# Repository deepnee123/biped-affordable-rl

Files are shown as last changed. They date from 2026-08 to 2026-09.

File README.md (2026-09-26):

# Low-Cost Bipedal Robot via Reinforcement Learning

A personal passion project focused on achieving robust bipedal locomotion using highly accessible, 3D-printed hardware, and machine learning control.

## Overview

This project aims to bridge the **Sim-to-Real** gap for low-cost, hobby-grade bipedal robotics. While high-end humanoid robots rely on multi-thousand-dollar custom actuators, this design explores how advanced **Reinforcement Learning (RL)** policies can compensate for physical hardware limitations. Uses digitigrade locomotion(fun fact: animals like ostriches don't actually have inverted knees, it's their ankle). 

---

## Current Project Status

- [x] **CAD & Structural Design:** Initial physical architecture conceptualized and modeled. 

- [x] **Hardware Prototyping:** Fabricated and assembled a single-leg testbed to validate software integration, joint range of motion, and motor actuation. Second leg to be fabricated after I receive the funds(hopefully)
- [x] **Simulation Environment Setup:** Porting robot kinematics to **Genesis World**. Simplified model for training: 

  - ~~*In Progress:* Fixing URDF joint limits, collision meshes, and inertia tensors to eliminate mesh explosions during physics step iterations.~~
  - ~~*In Progress:* URDF was too hard to deal with so switched over to MJCF successfully, now loads in MuJoCo visualizer perfectly. adjusted all parameters for motors, friction, weight etc for accuracy~~
Screenshot from 2026-09-06 18-59-11

- [/] **RL Policy Training:** Training locomotion policies in simulation using domain randomization.
  - currently training all movesets, planning on deploying into robot after I am able to fund and finish the hardware build.
  - implementing domain randomization such as variable COM and actuator friction 
- [ ] **Sim-to-Real Deployment:** Flashing trained policy weights to hardware for real-world locomotion tests.

please check these out! 
current training progress videos here!:

[here:](https://www.youtube.com/watch?v=r23alA2GN7E)
[randomized vector commands for full moveset here](https://www.youtube.com/watch?v=8FQqMWRTSfI)

## System Architecture

Hardware schematic:


### Hardware Specifications
* **Actuators:** custom BLDC actuators utilizing a high reduction 17:1 cycloidal drive in order to gear down a cheap drone 360kv BLDC motor from Aliexpress. Each actuator uses odrive mini motor controller clones also from aliexpress. Each motor controller uses Odrive 3.6 firmware uploaded using Odrive tool. [Click here for great motor controller setup tutorial](https://github.com/justlovescience/MKS-XDRIVE-MINI), make sure to setup in accordance to the motor you are using. In the future I may consider creating custom pcb's for motor controls, hopefully decreasing cost even more, but that is a project in it of itself.
* **Microcontroller / Brain:** ESP32, depending on how software training goes I may switch to ESP 32 CAM so the robot can see. talks to motors through a CAN wire going to all motor controllers
* **Power Delivery:** 6s 2200 mAH LiPo battery
* **Sensors:** 
  * Inertial Measurement Sensor(IMU) MPU 9250
  * Built in magnetic encoders on motor controllers 

### Software & Training Stack
* **CAD Design:** [Onshape]https://cad.onshape.com/documents/8bf57c6be62972ed6d80fc07/w/9d44f84c666fceecad986cd8/e/5c78cbb988f68fd2f32a2769
* **Simulation Engine:** [Genesis World Sim](https://github.com/Genesis-Embodied-AI/genesis-world)
* **Robot Description:** ~~Custom URDF model using Onshape to URDF tool~~ changed to using MJCF file since it supports parallel linkages without hassle and is also supported by Genesis world.

## Design Constraints & Engineering Goals

* **Affordable Bill of Materials (BOM):** Target total cost **under $1,200**, utilizing readily available consumer components sourced via Amazon and AliExpress.
* **Accessiblity:** Fully 3D-printable structural components optimized for cheap materials(PC PETG blend) without requiring specialized CNC aluminum parts.
* **"Blind" Locomotion:** Rely exclusively on IMU body orientation and joint state feedback to maintain balance.
* **Dynamic Movement:** Develop policy reward functions capable of transitioning the robot through walking, running, and jumping states while preserving balance.

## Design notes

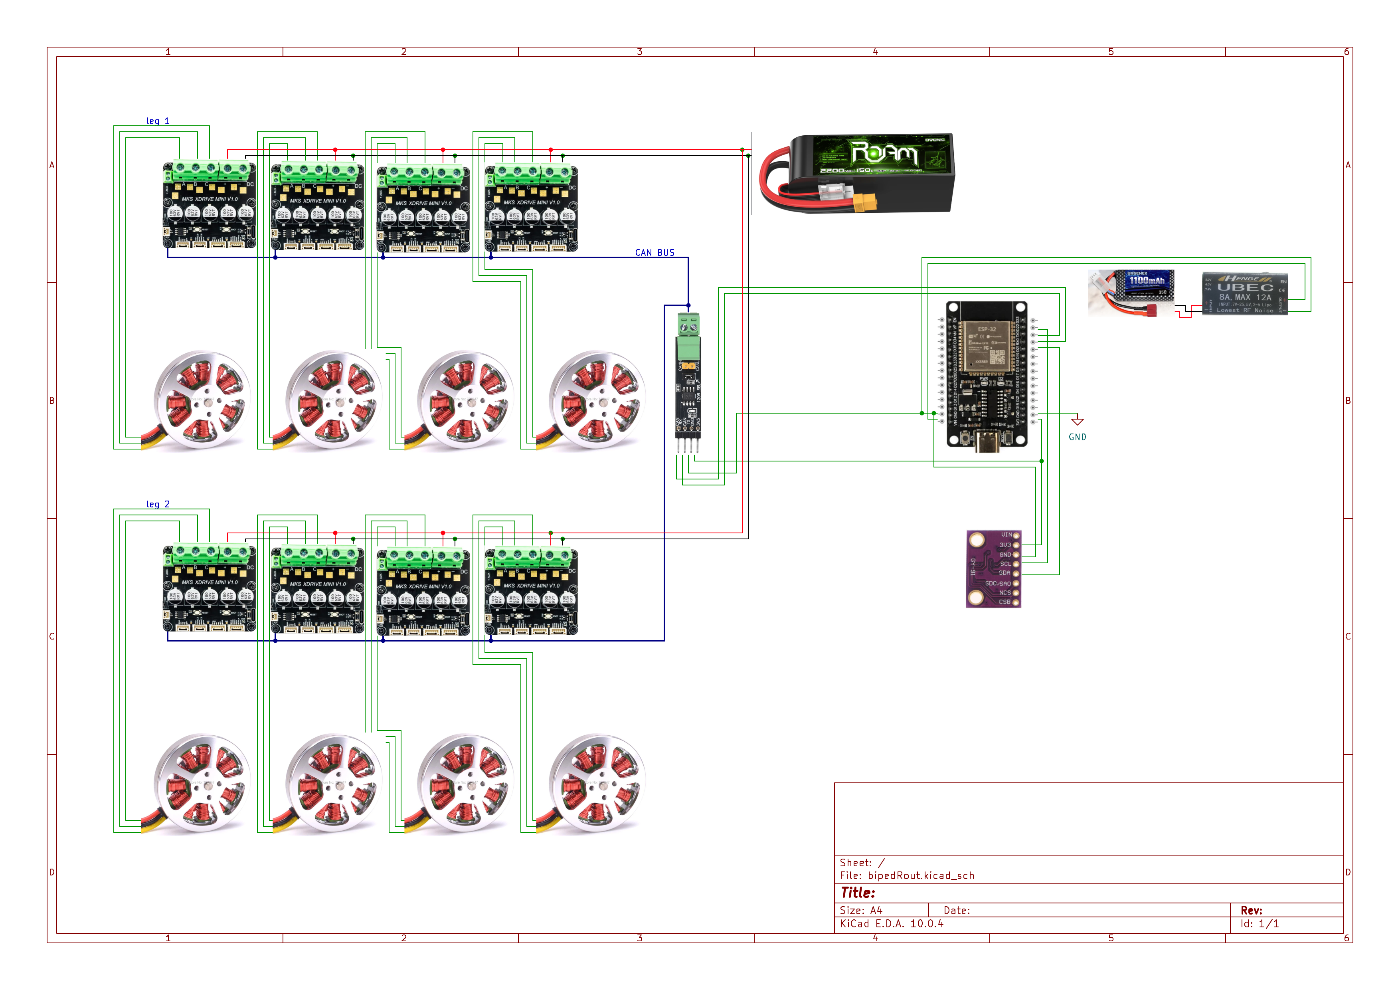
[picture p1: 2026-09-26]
image.png

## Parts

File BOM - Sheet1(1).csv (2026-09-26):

name | price(total) | quantity | brand/seller | total:
brass inserts | 13.99 | 1
2s lipo 1100 mAH | 20 | 1
3x ESP32 devkitC | 16.99 | 1
Heat shrinks | 5.99
roll of 12 awg wire | 15.99
20x 6809ZZ bearings | 47.58 | 1 | uxcell
20x Diametric magnets | 19.33 | 1 | Eliveshown
6s Lipo Charger | 29.99 | 1 | ISDT
6s Lipo 2200mAH | 34.99 | 1 | Ovonic
10x XT60 connector male + female | 9.99 | 1 | Tosiicop
2x PC filament 1kg | 47.98 | 1 | CC3D
m3 screws long | 8.99 | 1
8x 5010 360kv motor | 120 | 1
8x MKS xdrive mini | 400 | 1 | Makerbase
2x steel linkage | 15.28 | 1 | MECCANIXITY
80x MR106-RS bearings | 48.95 | 1 | Sackorange
20x 6701-2RS bearings | 19.58 | 1 | uxcell
SN65HVD230 | 7.99 | 1
misc screws/washers/nuts, soldering iron, etc | 67
 |  |  |  | 950.61

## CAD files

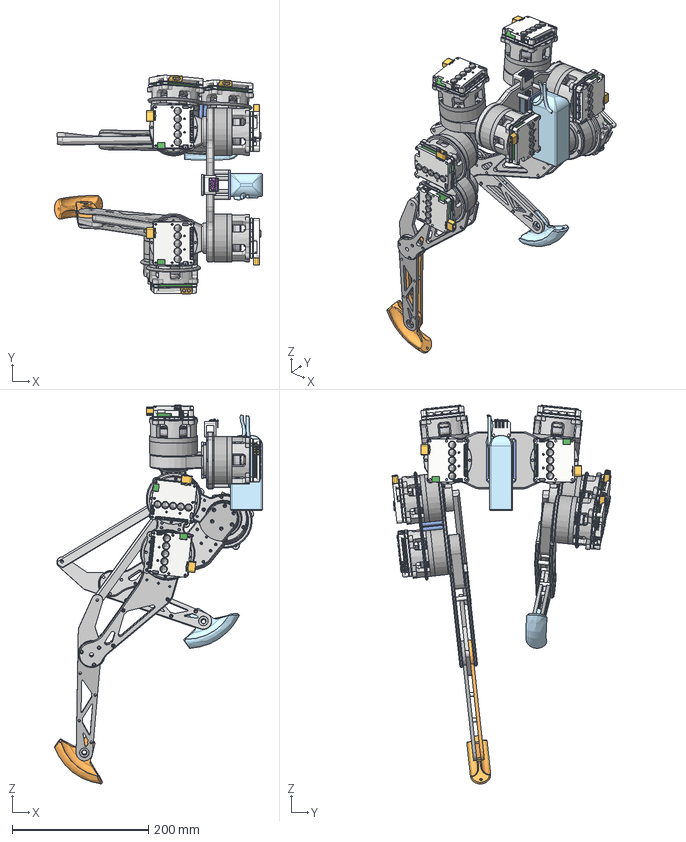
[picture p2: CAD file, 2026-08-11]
full assembly v3.step
305.0 x 320.7 x 555.5 mm
mounting
spacer x 4
cover
foot
upper leg spacer x 8
joint x 4
insert side x 2
linkage x 2
mid leg spacer x 4
screw side x 2
insert side lower leg
screwside
actuator mount x 4
lower leg spacer x 4
screw side lower leg
motor mount x 2
????? ?? ?????? 5010 x 8
?????? ?? ?????? 5010 x 8
insertside x 2
linkage attachement x 2
screw side lower leg-Mirrored
screwside-Mirrored
insert side lower leg-Mirrored
foot-Mirrored
SM02B-GHS-TB x 40
SM06B-GHS-TB x 144
SM05B-GHS-TB x 128
mks odrive mini xt60 x 64
Contact x 16
Housing x 8
1-copper x 768
Board x 56
16-copper x 96
16-soldermask x 8
1-soldermask x 8
capicitor_10x10.5x4 x 40
Base_?10Capacitor x 40
Cover x 16
Terminal x 64
Stem x 16
Frame x 16
42899.f3d x 8
632722110112_Pin_2 x 128
632722110112_Cap x 8
632722110112_Pin_1 x 32
632722110112_Pin_3 x 32
632722110112_Shielding_3 x 16
632722110112_Shielding_2 x 16
632722110112_Shielding x 8
632722110112_Housing x 8
PIN x 30
RESISTOR1_2 x 11
PCB
RESISTOR2-32_2 x 2
TRANSISTOR_3-LEG_2
RECTANGULARCHIP_2
BUTTONFLASH-13_2 x 2
BUTTONFLASH-14_2 x 2
USB_SOCKET_2
TRANSISTOR_3-LEG2_2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

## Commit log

2026-07-05 Revise README with project details and goals
    Updated project title and added detailed description, current state, and system constraints.
2026-08-11 added BOM and some CAD files
    [BOM - Sheet1.csv, full assembly v3.step]
2026-08-18 Revise README for clarity and project updates
    Updated project overview, current status, and system architecture sections in README.
2026-08-18 Enhance README with images for project status
    Added images to project status updates for CAD design and simulation environment setup.
2026-09-06 Update README with hardware diagram and specs
    Added a hardware diagram and specifications for the robot leg.
2026-09-06 Enhance actuator specifications in README
    Expanded actuator section with additional details on motor controller setup and future plans for custom PCBs.
2026-09-06 Revise BOM - Sheet1.csv with new entries
    Updated BOM to include new items and corrected formatting.
    [BOM - Sheet1.csv]
2026-09-06 Update actuator specifications in README.md
2026-09-06 Revise simulation environment setup in README
    Updated simulation environment setup details, switched from URDF to MJCF for better compatibility with MuJoCo visualizer, and adjusted parameters for accuracy.
2026-09-11 Update README with training progress details
    Added current training progress section with a link to a video.
2026-09-12 Revise README for training updates and resources
    Updated README with current training progress and video links.
2026-09-26 Update hardware schematic section in README
    Removed a note about the schematic and clarified the hardware diagram section.
2026-09-26 Replace hardware schematic image link
    Updated hardware schematic image in the README.
2026-09-26 added hardware wiring schematic
2026-10-16 Delete calibrate_pose.py
    no longer needed
2026-10-16 Rename full assembly v3.step to CAD/full assembly v3.step
2026-10-16 edited structure and fully updated BOM
2026-10-16 Revise BOM with new items and pricing details
    Updated BOM with new items and prices, including links and notes.
2026-10-16 Update README with IRL progress details
    Added information about IRL progress and motor movement.
2026-10-16 Revise README with latest project updates
    Updated the README to reflect current IRL progress and simulation adjustments.
2026-10-19 Fix duplicate joint name in biped_move.py
    Updated joint name from 'leg4' to 'leg4R' to avoid duplication.
2026-10-22 Add Arduino test for actuator control with ODrive
2026-10-22 Add actuator details specification to README
2026-10-22 Revise actuator details and torque calculations
    Updated actuator details with motor specifications and torque calculations.
2026-10-22 Fix wording in actuator details section
    Corrected wording for clarity regarding torque calculations.
2026-10-22 Add ODrive settings for velocity and position control
    Added tweaked settings for ODrive configuration including velocity and position control modes.
2026-10-22 Revise actuator specifications and tutorial links
    Updated actuator setup tutorial link and added web GUI reference.
2026-10-23 added actuator cad file as well
2026-10-24 Revise actuator details and performance metrics
    Updated actuator specifications and performance calculations, adjusting motor current limits and torque outputs based on testing results. Added discussion on discrepancies between theoretical and exp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
2026-10-24 Add future improvement suggestion for actuator design
2026-10-29 Update README with reviewer note and actuator details
    Added reviewer note and updated actuator specifications.
